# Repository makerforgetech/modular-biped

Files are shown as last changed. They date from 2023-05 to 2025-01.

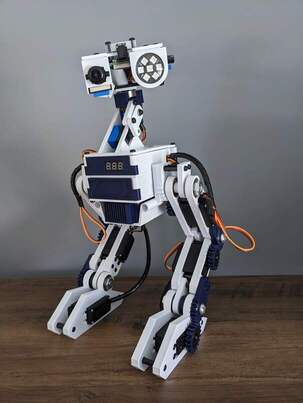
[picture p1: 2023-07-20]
images/full_project_front_thumb.jpg

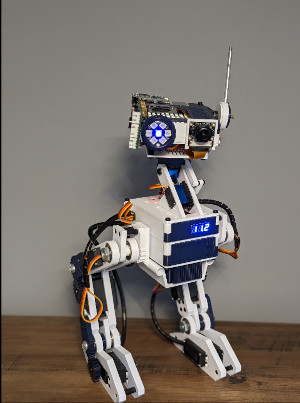
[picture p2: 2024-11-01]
images/full_project_front_pi5_thumb.jpg

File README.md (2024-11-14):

# Open Source, 3D Printable, Modular Bipedal Robot Project

The **Modular Bipedal Robot** project aims to educate and inspire individuals interested in robotics and electronics. This open-source initiative focuses on creating a fully autonomous companion robot with a variety of advanced features.

## Key Features

- **Bipedal Design**: The robot includes articulated legs for bipedal movement.
- **Control Systems**: Utilizes Arduino and Raspberry Pi, managed through custom PCBs.
- **Modular Body**: Configurable body components allow for easy customization and adaptability.
- **Software Modules**:
  - Animation: Handles the animation of the robot, including walking, turning, and other movements.
  - Braillespeak: Converts text to Braille and speaks it using a proprietary audio output using the onboard buzzer.
  - Buzzer: Controls the buzzer for audio output. Includes the ability to play tones and melodies.
  - ChatGPT: Uses the OpenAI GPT models to process text based on user input.
  - Logging: Logs data to a file for debugging and analysis.
  - Motion Detection: Handles motion detection using an onboard microwave motion sensor.
  - Neopixel: Controls the onboard Neopixel LEDs for visual feedback.
  - PiServo: Controls the servos connected to the Raspberry Pi.
  - PiTemperature: Reads the temperature from the integrated temperature sensor on the Raspberry Pi.
  - RTLSDR: Uses an RTL-SDR dongle to receive and process radio signals.
  - Serial Connection: Handles serial communication between the Raspberry Pi and Arduino.
  - Servos: Controls the servos connected to the Arduino via the Raspberry Pi and the serial connection.
  - Tracking: Uses computer vision to track objects and faces using the onboard camera.
  - Translator: Translates text between languages using the Google Translate API.
  - TTS: Converts text to speech using the onboard speaker.
  - Viam: Uses the VIAM API to integrate Viam modules for additional functionality.
  - Vision: Handles image processing and computer vision tasks using the onboard IMX500 Raspberry Pi AI camera.
  - [Read more](https://github.com/makerforgetech/modular-biped/wiki/Software#modules)!

## Project Background

The Modular Biped Robot Project is designed to provide a flexible and modular framework for robotics development using Python and C++ on the Raspberry Pi and Arduino platforms. It aims to enable developers, robotics enthusiasts, and curious individuals to experiment, create, and customize their own biped robots. With a range of features and functionalities and the option to add your own easily, the Modular Biped Robot Project offers an exciting opportunity to explore the world of robotics.

## Modularity

The open source framework is designed for flexibility, allowing users to easily add or remove components to suit their specific needs. Comprehensive [guides](https://github.com/makerforgetech/modular-biped/wiki/Software#creating-a-module) are provided for integrating new modules seamlessly.

## Resources

- **Documentation**: For detailed information, visit the project’s GitHub wiki: [Modular Biped Documentation](https://github.com/makerforgetech/modular-biped/wiki)
- **Code**: Check out the modular open source software on [GitHub](https://github.com/makerforgetech/modular-biped)
- **YouTube Playlist**: Explore the development process through our build videos: [Watch on YouTube](https://www.youtube.com/watch?v=2DVJ5xxAuWY&list=PL_ua9QbuRTv6Kh8hiEXXVqywS8pklZraT)
- **Community**: Have a question or want to show off your build? Join the communities on [GitHub](https://bit.ly/maker-forge-community) and [Discord](https://bit.ly/makerforge-community)!

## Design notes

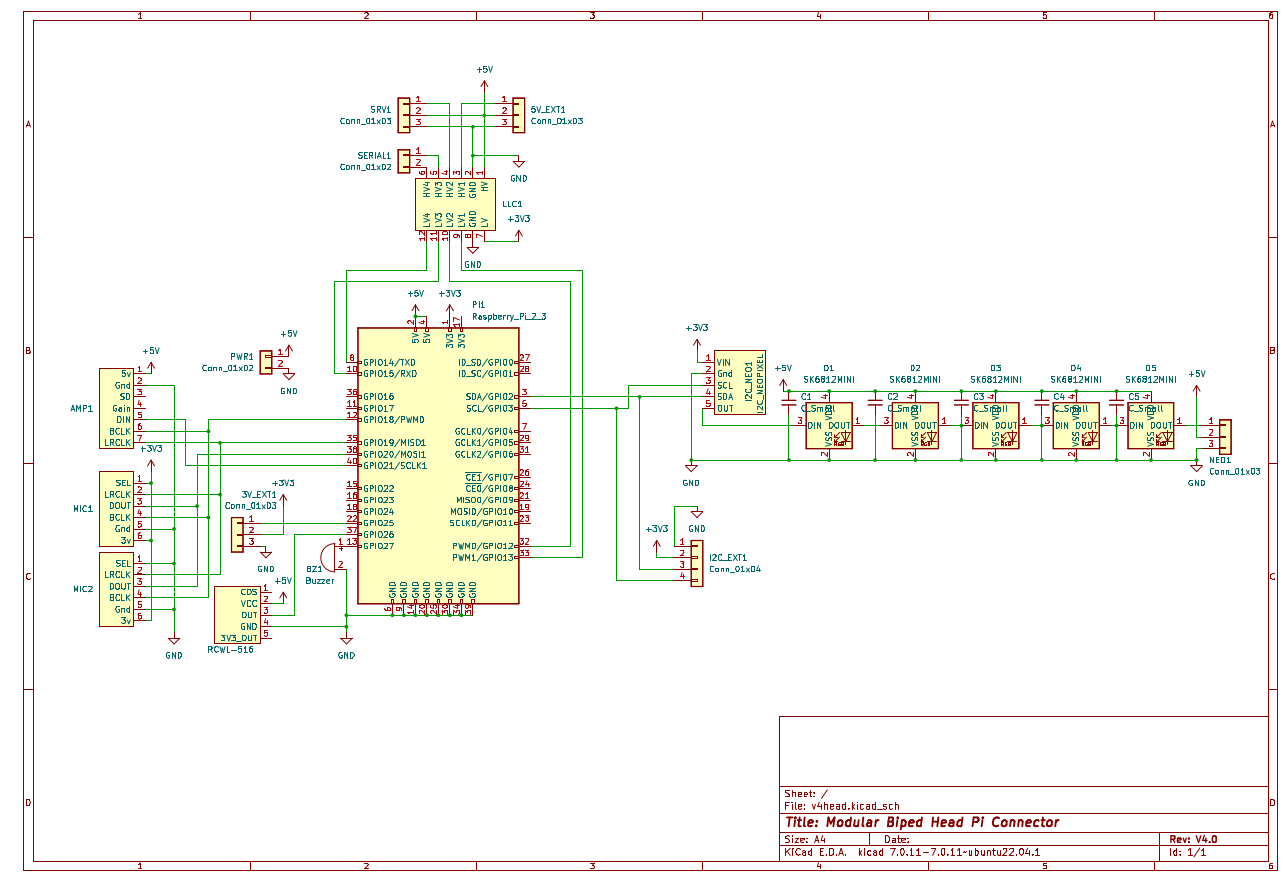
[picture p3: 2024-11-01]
circuits/v4/Head/head_schematic.png

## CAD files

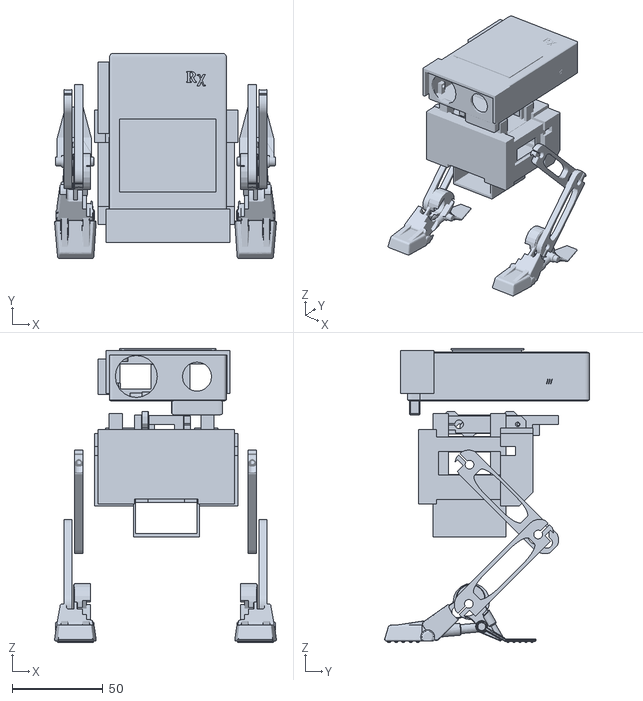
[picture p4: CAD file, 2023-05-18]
3d_prints/v2/complete.stl
122.0 x 112.7 x 161.6

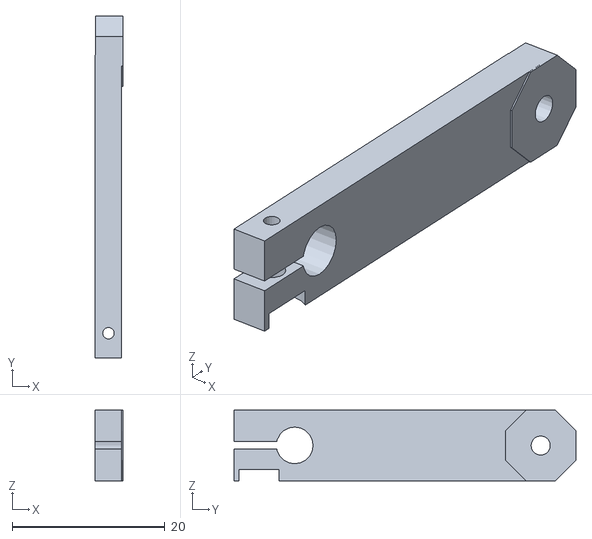
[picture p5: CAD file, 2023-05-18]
3d_prints/v2/neck_extension.stl
3.60 x 44.8 x 9.25

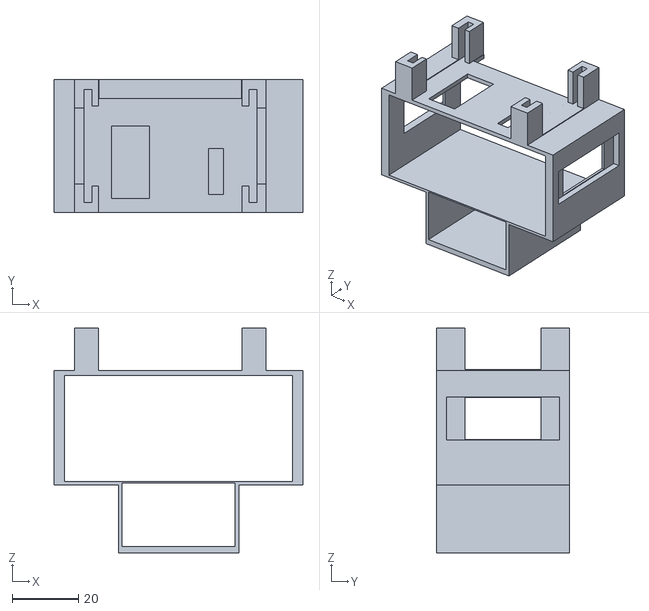
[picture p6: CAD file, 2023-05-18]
3d_prints/v2/skeleton.stl
75.0 x 40.0 x 67.8

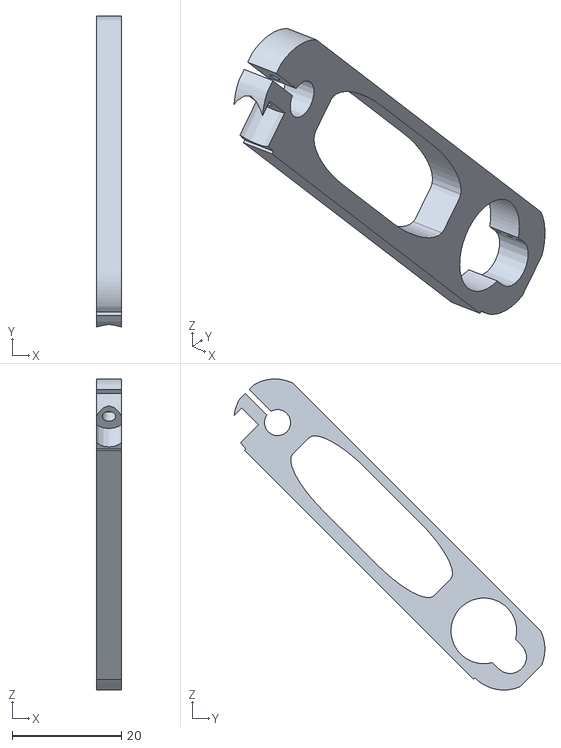
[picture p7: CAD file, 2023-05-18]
3d_prints/v2/right_leg_upper.stl
4.50 x 56.9 x 56.9

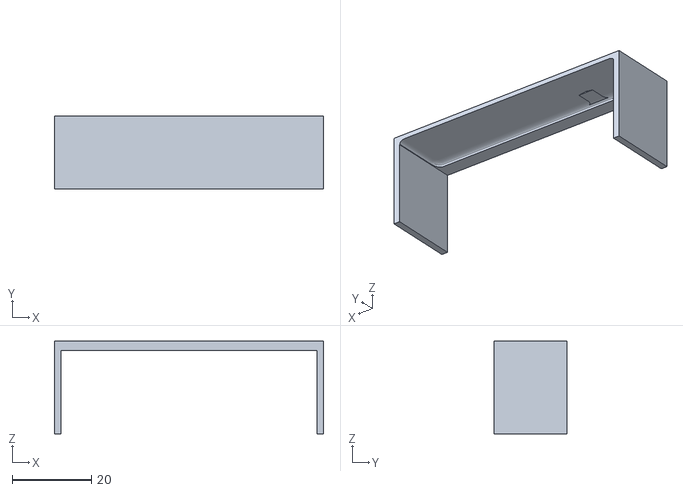
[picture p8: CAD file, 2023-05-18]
3d_prints/v2/head_visor.stl
68.0 x 18.5 x 23.5

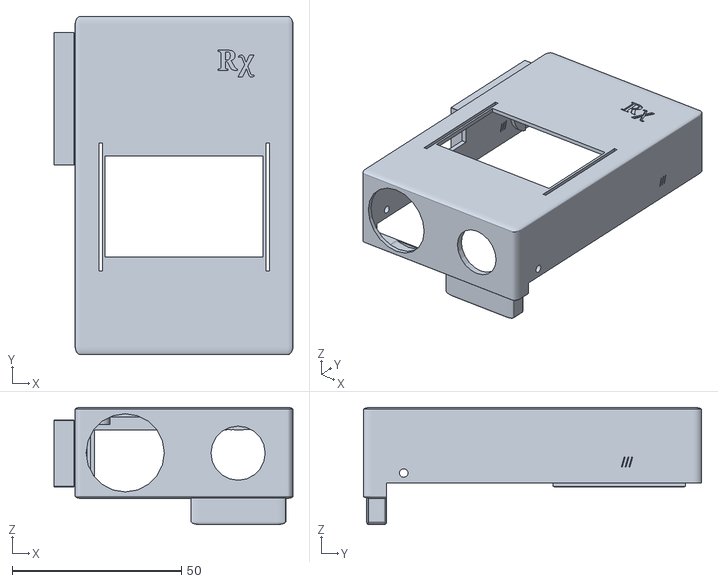
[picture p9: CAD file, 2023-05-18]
3d_prints/v2/head_top.stl
70.6 x 100.0 x 34.7

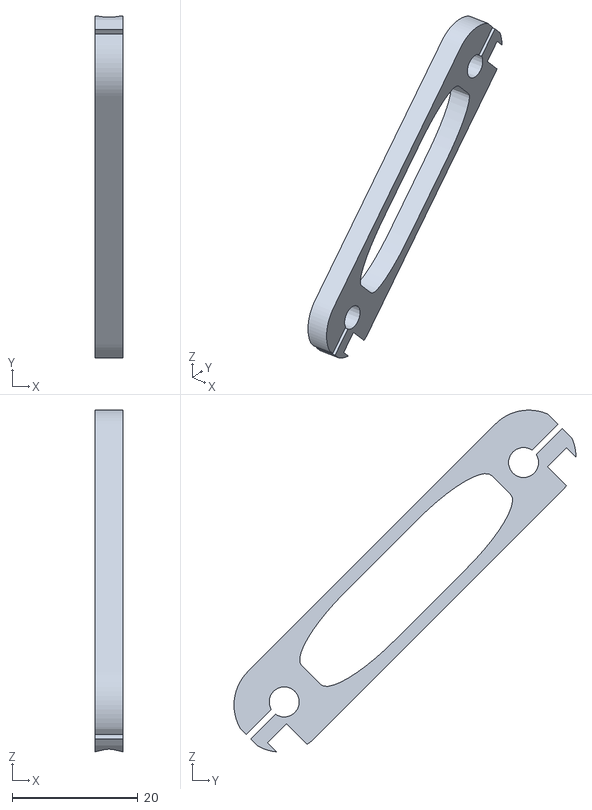
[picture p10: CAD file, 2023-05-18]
3d_prints/v2/left_leg_lower.stl
4.50 x 54.4 x 54.4

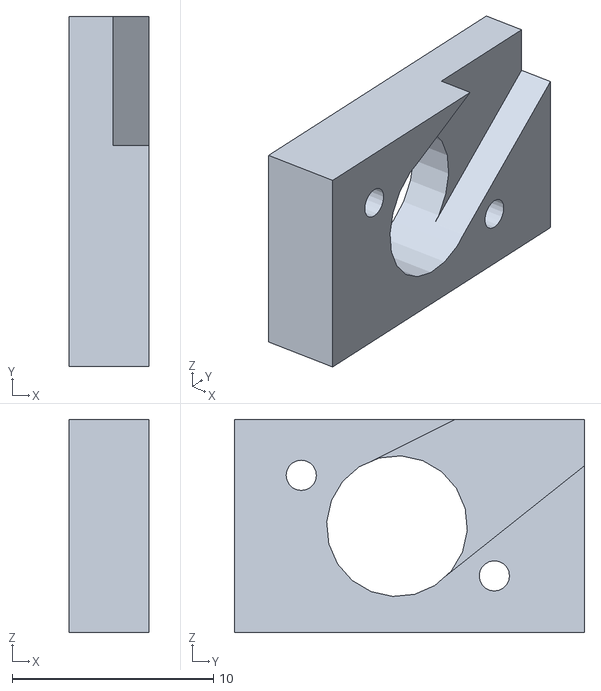
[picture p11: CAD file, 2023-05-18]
3d_prints/v2/neck_tilt_mount.stl
4.00 x 17.4 x 10.6

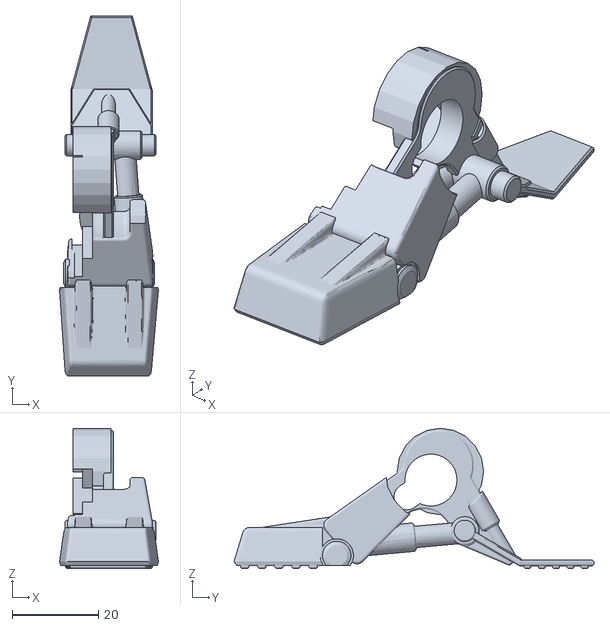
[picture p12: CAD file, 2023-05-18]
3d_prints/v2/left_foot.stl
22.9 x 83.3 x 32.5

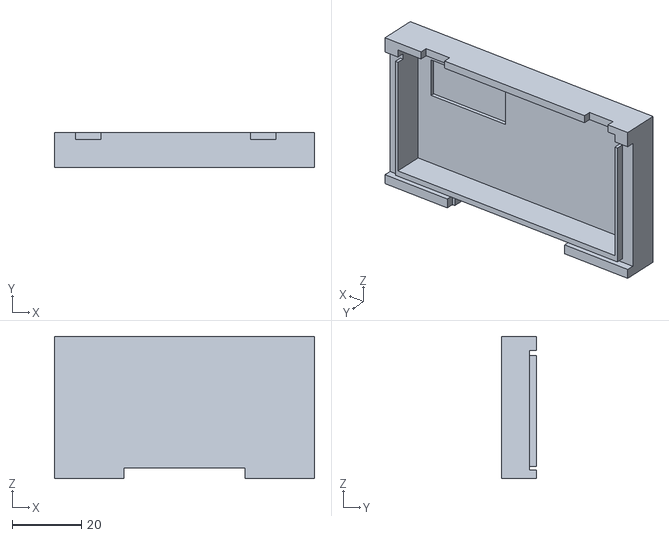
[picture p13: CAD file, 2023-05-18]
3d_prints/v2/front_case.stl
75.0 x 10.0 x 41.0

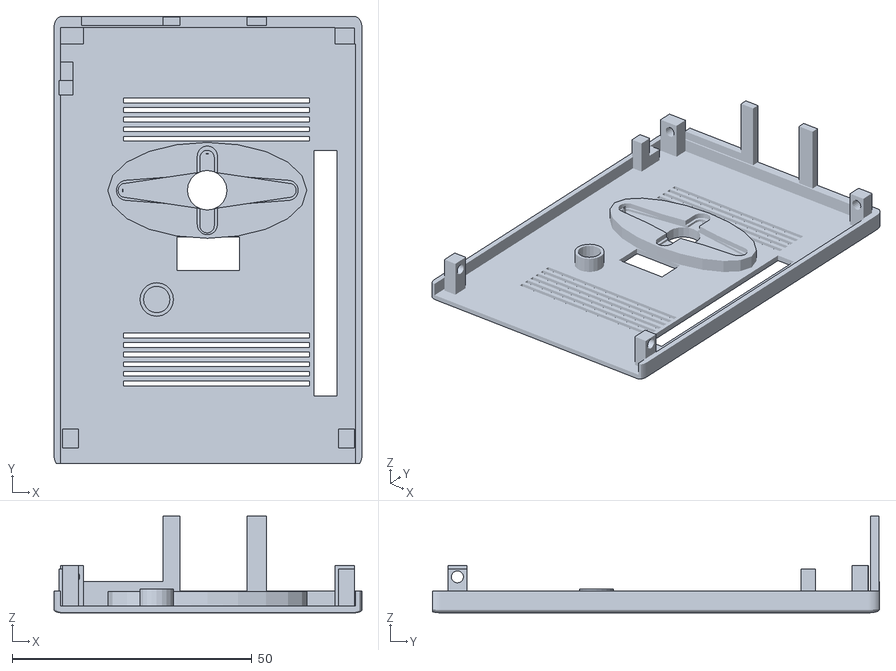
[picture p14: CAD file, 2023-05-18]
3d_prints/v2/head_bottom.stl
64.2 x 93.2 x 20.1

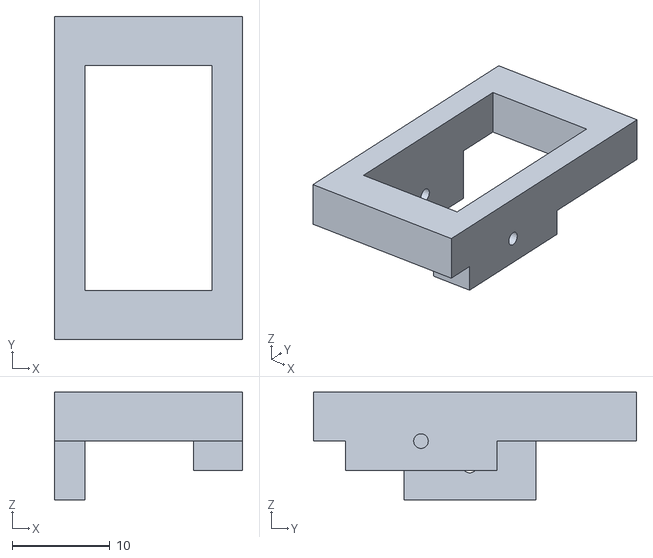
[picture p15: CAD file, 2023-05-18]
3d_prints/v2/neck_servo_mount.stl
19.2 x 33.0 x 11.0

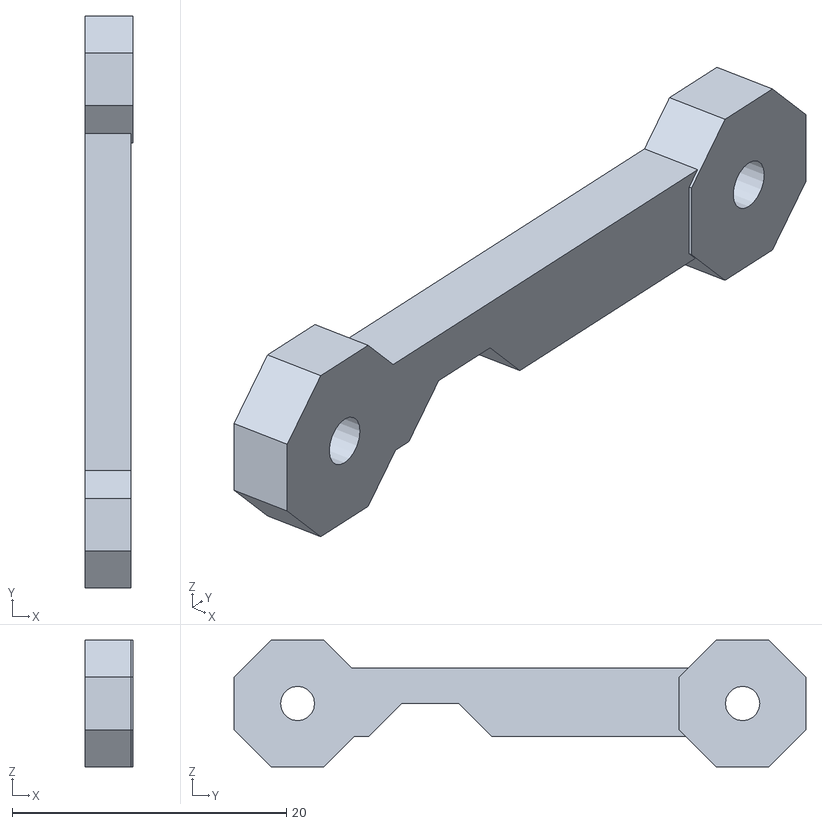
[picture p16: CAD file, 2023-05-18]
3d_prints/v2/neck_tilt_upper.stl
3.50 x 41.7 x 9.24

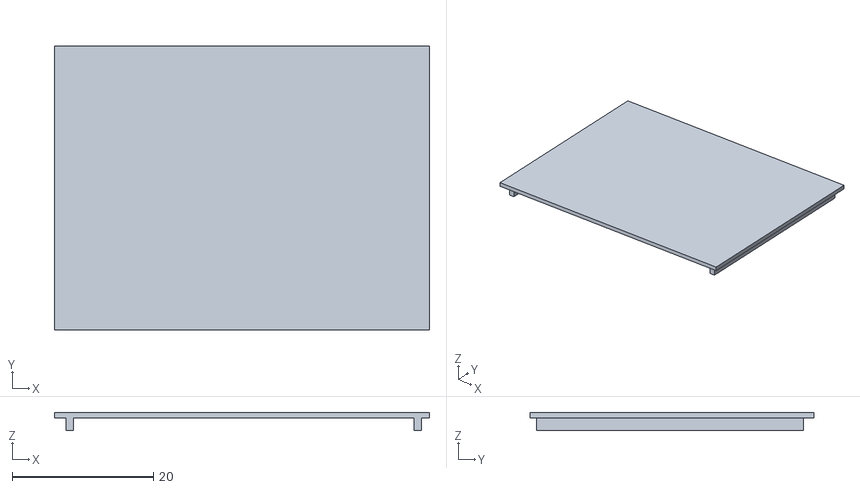
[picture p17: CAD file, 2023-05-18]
3d_prints/v2/head_lid.stl
53.1 x 40.2 x 2.60

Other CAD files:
3d_prints/v2/left_leg_upper.stl
3d_prints/v2/right_leg_lower.stl
3d_prints/v2/right_foot.stl
3d_prints/v2/back_case.stl
3d_prints/v2/neck_tilt_lower.stl

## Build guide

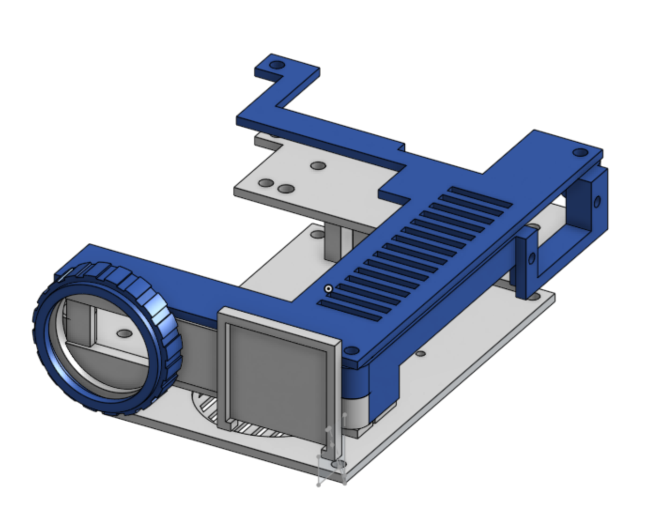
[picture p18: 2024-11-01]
images/assembly_head.png

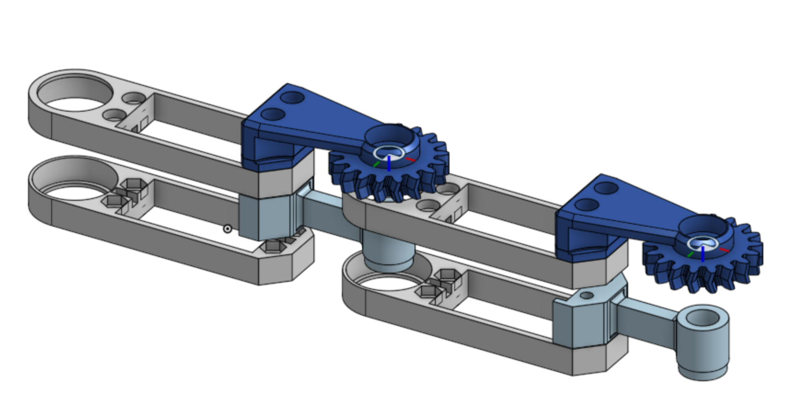
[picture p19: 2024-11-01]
images/assembly_leg.png

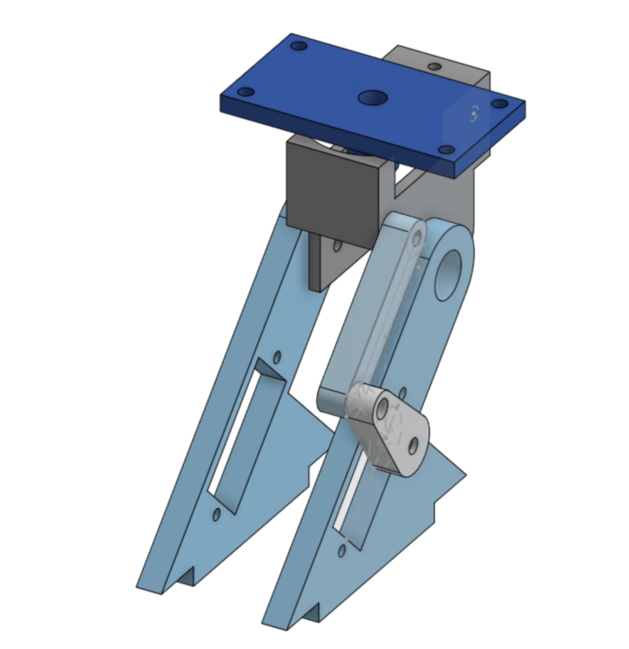
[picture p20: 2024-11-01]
images/assembly_neck.png

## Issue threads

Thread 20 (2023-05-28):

Serial communication between Pi and Arduino

danic85, 2023-05-28:
In branch `v3`, the code has not been fully updated to allow the Pi to take control of the arduino servo positions and suspend random animations from the arduino.

Impact:
The face tracking will not function, or any animations initiated from the Pi.

Additionally, the battery monitor is not implemented in code, although the code for v2 is in place on the Pi.

danic85, 2023-05-29:
I have started a new feature branch for this work until it is stable, progress here:

https://github.com/dmt-labs/modular-biped/pull/21/files

Closed 2023-07-18.

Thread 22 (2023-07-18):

Low battery monitor non-functional

danic85, 2023-07-18:
This has not been updated since v2. Code exists but has not been tested.

danic85, 2024-10-31:
Archiving as this module is not currently in use.

Closed 2024-10-31.

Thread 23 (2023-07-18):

Raspberry Pi Leg control disabled

danic85, 2023-07-18:
See PR:

https://github.com/dmt-labs/modular-biped/pull/21#discussion_r1214812900

This can be re-enabled but it has not been tested.

Currently Arduino is solely responsible for leg positions

danic85, 2024-10-31:
This is no longer the case: although the Pi does not currently control the servos, it can if needed

Closed 2024-10-31.

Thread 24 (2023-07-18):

Face tracking issues

danic85, 2023-07-18:
In v3 the face tracking is not functioning correctly.

The code exists from v2 but has not been adjusted to work with new hardware.

Current behaviour is the head moves to attempt to track face but is not entirely successful.

danic85, 2023-07-31:
This has been updated and works reliably with `debug` mode activated in the vision config. When other modules are also enabled the tracking becomes unpredictable.

Closed 2024-10-31.

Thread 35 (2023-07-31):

Speech recognition issues

danic85, 2023-07-31:
When using speech recognition on `develop` branch an error occurs that not only crashes the app but also causes the Raspberry Pi taskbar to disappear. There is no way to recover this that I can find.

I will add the error here once I can get a copy.

I have disabled the module in `develop` temporarily.

danic85, 2023-07-31:
Similar issue: https://github.com/Uberi/speech_recognition/issues/71

Closed 2024-10-31.

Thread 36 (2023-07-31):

Occasional error when testing i2c neopixels

danic85, 2023-07-31:
There is an error with the i2c neopixel driver when the script is executed multiple times. It appears to be related to the software needing to release the hardware before it can be used again.

Error will be posted soon.

Workaround is to wait for a few seconds then try again.

danic85, 2024-10-31:
Closing as this does not have a major impact, and I haven't seen it recently.

Closed 2024-10-31.

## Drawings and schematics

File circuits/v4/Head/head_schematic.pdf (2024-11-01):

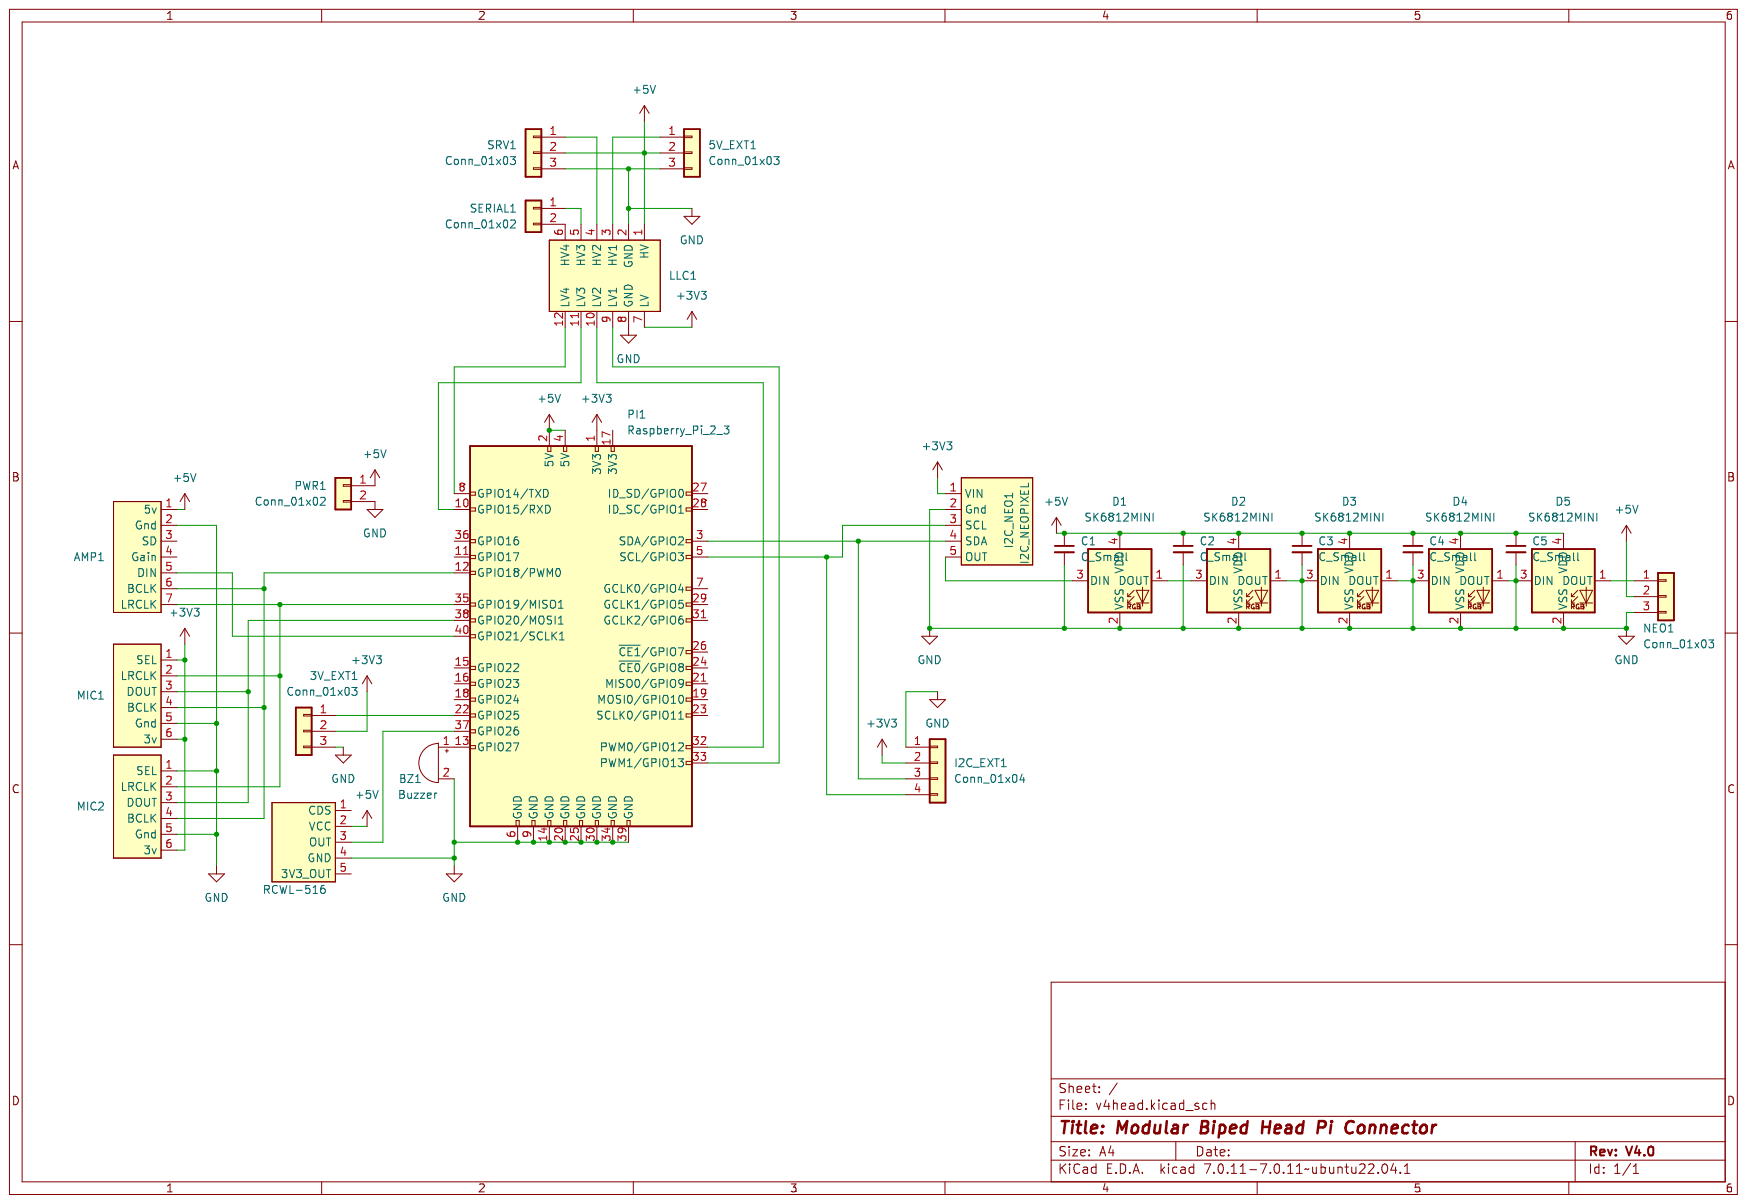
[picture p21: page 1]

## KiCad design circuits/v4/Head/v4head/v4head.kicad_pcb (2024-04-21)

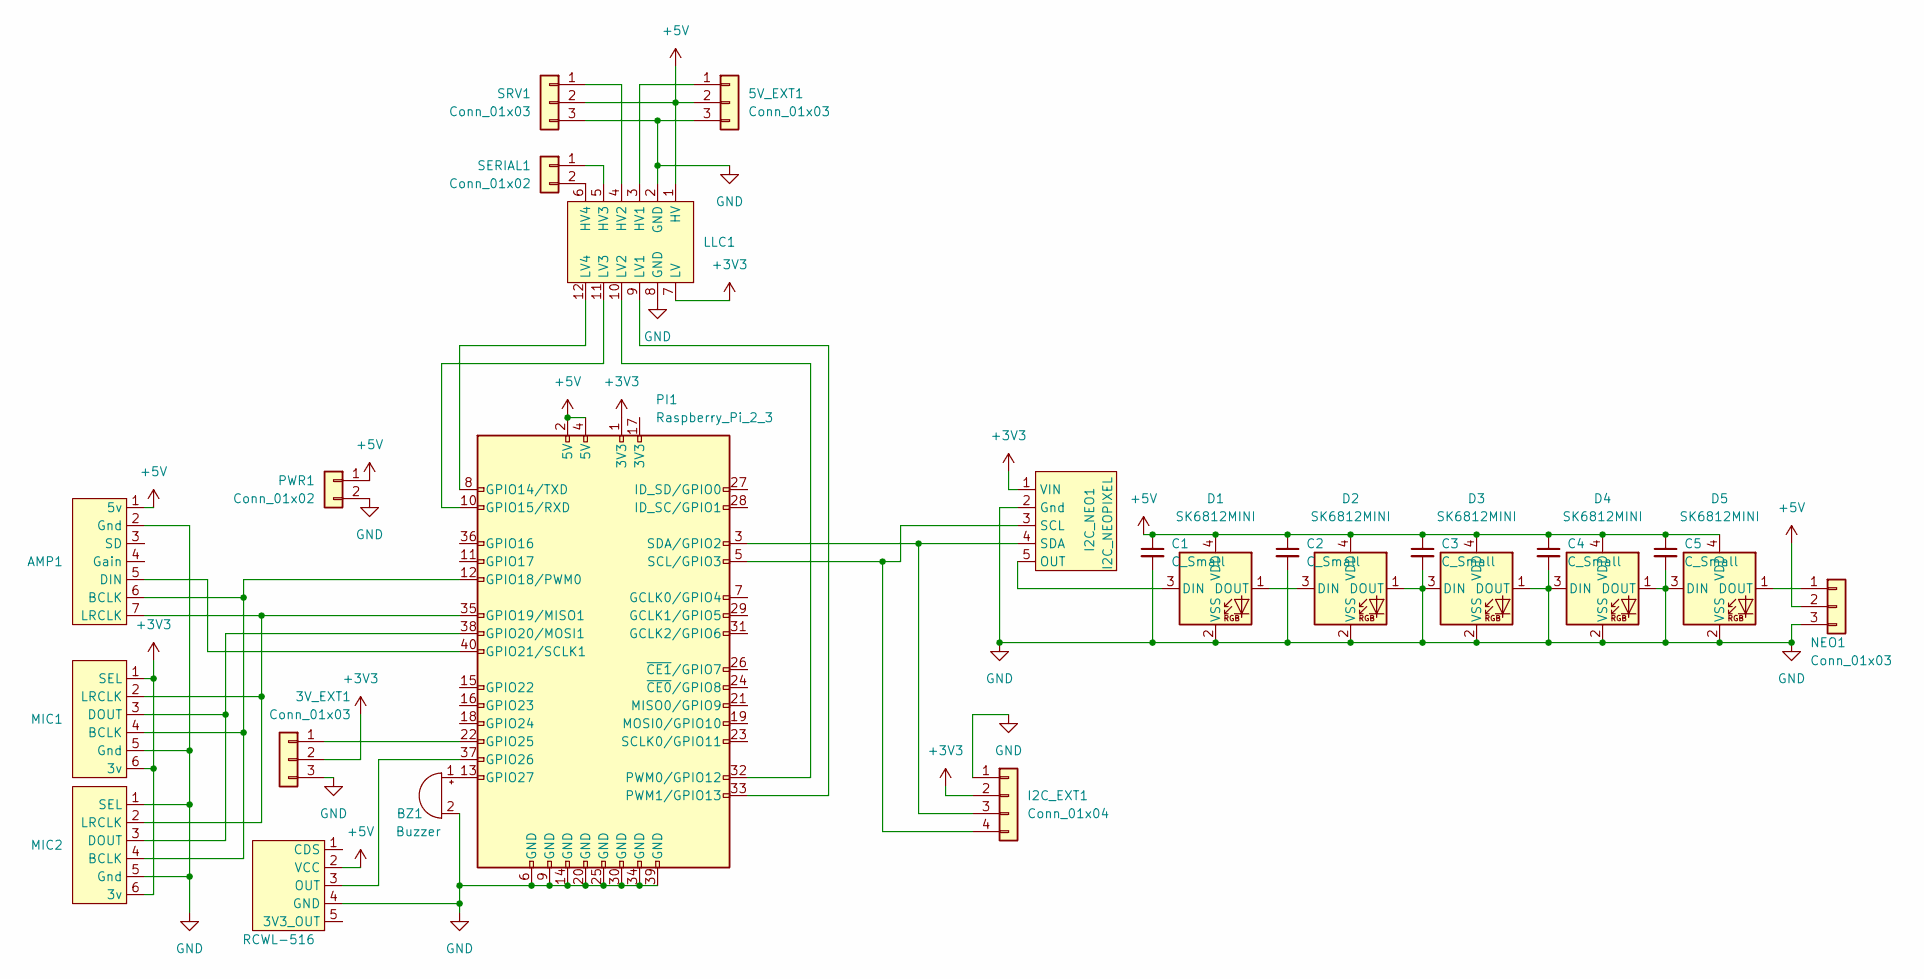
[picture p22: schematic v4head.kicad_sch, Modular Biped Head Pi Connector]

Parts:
3V_EXT1, 5V_EXT1: Conn_01x03; JST_XH_B3B-XH-A_1x03_P2.50mm_Vertical
AMP1: MAX98357
BZ1: Buzzer; Buzzer_12x9.5RM7.6
C1, C2, C3, C4, C5: C_Small; C_0201_0603Metric
D1, D2, D3, D4, D5: SK6812MINI; LED_SK6812MINI_PLCC4_3.5x3.5mm_P1.75mm
I2C_EXT1: Conn_01x04; JST_XH_B4B-XH-A_1x04_P2.50mm_Vertical
I2C_NEO1: I2C_NEOPIXEL
LLC1: LCC_BIDIRECTIONAL
MIC1, MIC2: SPH0645LM4H
NEO1: Conn_01x03; JST_XH_B3B-XH-A_1x03_P2.50mm_Vertical
PI1: Raspberry_Pi_2_3; PinHeader_2x20_P2.54mm_Vertical
PWR1: Conn_01x02; JST_XH_B2B-XH-A_1x02_P2.50mm_Vertical
RCWL-516: RCWL-0516_MIN
SERIAL1: Conn_01x02; JST_XH_B2B-XH-A_1x02_P2.50mm_Vertical
SRV1: Conn_01x03; PinHeader_1x03_P2.54mm_Vertical

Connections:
+3V3: 3V_EXT1.2, I2C_EXT1.2, I2C_NEO1.1 (VIN), LLC1.7 (LV), MIC1.1 (SEL), MIC1.6 (3v), MIC2.6 (3v), PI1.1 (3V3)
+5V: 5V_EXT1.2, AMP1.1 (5v), C1.1, C2.1, C3.1, C4.1, C5.1, D1.4 (VDD), D2.4 (VDD), D3.4 (VDD), D4.4 (VDD), D5.4 (VDD), LLC1.1 (HV), NEO1.2, PI1.2 (5V), PI1.4 (5V), PWR1.1, RCWL-516.2 (VCC), SRV1.2
GND: 3V_EXT1.3, 5V_EXT1.3, AMP1.2 (Gnd), BZ1.2 (+), C1.2, C2.2, C3.2, C4.2, C5.2, D1.2 (VSS), D2.1 (DOUT), D2.2 (VSS), D3.1 (DOUT), D3.2 (VSS), D3.3 (DIN), D4.1 (DOUT), D4.2 (VSS), D4.3 (DIN), D5.2 (VSS), D5.3 (DIN), I2C_EXT1.1, I2C_NEO1.2 (Gnd), LLC1.2 (GND), LLC1.8 (GND), MIC1.5 (Gnd), MIC2.1 (SEL), MIC2.5 (Gnd), NEO1.3, PI1.6 (GND), PI1.9 (GND), PI1.14 (GND), PI1.20 (GND), PI1.25 (GND), PI1.30 (GND), PI1.34 (GND), PI1.39 (GND), PWR1.2, RCWL-516.4 (GND), SRV1.3
unnamed: 3V_EXT1.1, PI1.22 (GPIO25)
unnamed: 5V_EXT1.1, LLC1.3 (HV1)
unnamed: AMP1.6 (BCLK), MIC1.4 (BCLK), MIC2.4 (BCLK), PI1.12 (GPIO18/PWM0)
unnamed: AMP1.5 (DIN), PI1.40 (GPIO21/SCLK1)
unnamed: AMP1.7 (LRCLK), MIC1.2 (LRCLK), MIC2.2 (LRCLK), PI1.35 (GPIO19/MISO1)
unnamed: BZ1.1 (-), PI1.13 (GPIO27)
unnamed: D1.3 (DIN), I2C_NEO1.5 (OUT)
unnamed: D1.1 (DOUT), D2.3 (DIN)
unnamed: D5.1 (DOUT), NEO1.1
unnamed: I2C_EXT1.3, I2C_NEO1.4 (SDA), PI1.3 (SDA/GPIO2)
unnamed: I2C_EXT1.4, I2C_NEO1.3 (SCL), PI1.5 (SCL/GPIO3)
unnamed: LLC1.4 (HV2), SRV1.1
unnamed: LLC1.5 (HV3), SERIAL1.1
unnamed: LLC1.6 (HV4), SERIAL1.2
unnamed: LLC1.9 (LV1), PI1.33 (PWM1/GPIO13)
unnamed: LLC1.10 (LV2), PI1.32 (PWM0/GPIO12)
unnamed: LLC1.11 (LV3), PI1.10 (GPIO15/RXD)
unnamed: LLC1.12 (LV4), PI1.8 (GPIO14/TXD)
unnamed: MIC1.3 (DOUT), MIC2.3 (DOUT), PI1.38 (GPIO20/MOSI1)
unnamed: PI1.37 (GPIO26), RCWL-516.3 (OUT)

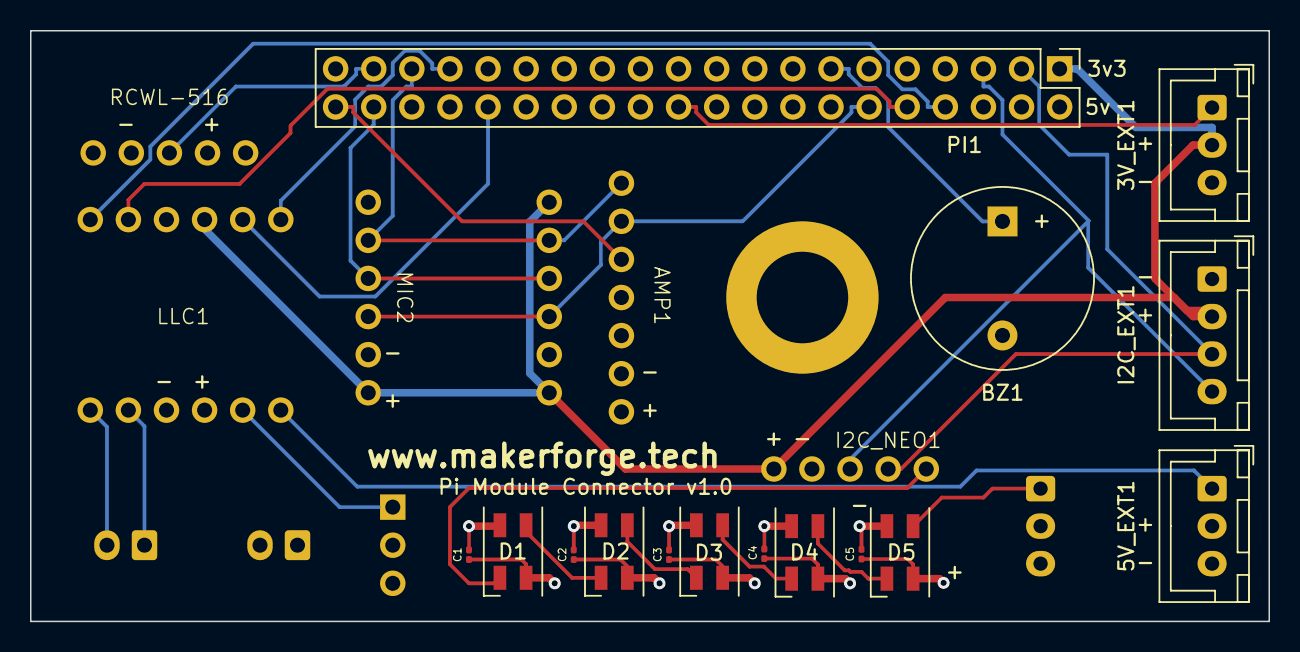
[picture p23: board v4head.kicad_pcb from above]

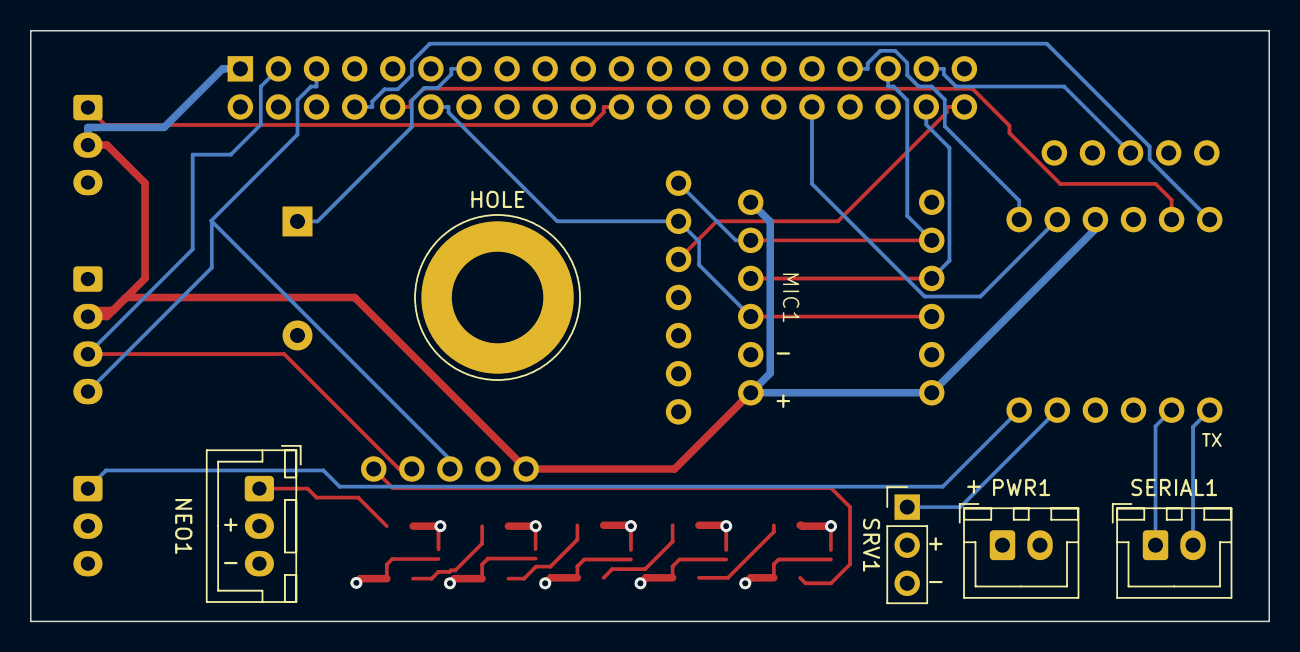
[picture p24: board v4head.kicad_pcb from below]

Board: 4 copper layers, 82.5 x 39.4 mm, 26 parts (6 on the bottom side), 23 nets.

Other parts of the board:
HOLE: Banana_Jack_1Pin

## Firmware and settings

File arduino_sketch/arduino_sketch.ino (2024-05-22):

/**
 * @file arduino_sketch2.ino
 * @brief Arduino sketch to control a 9 servo robot
 * @details This sketch animates a 9 servo bipedal robot using the ServoEasing library.
 * See the README.md file for more information.
 */

#include <Arduino.h>
#include "ServoEasing.hpp" // Must be here otherwise method fails: setEaseToForAllServosSynchronizeAndStartInterrupt
#include "Config.h"
#include "Order.h"
#include "PiConnect.h"
#include "ServoManager.h"
#ifdef MPU6050_ENABLED
#include "Mpu6050.h"
#endif

// #define DEBUG

PiConnect pi;
ServoManager servoManager;
#ifdef MPU6050_ENABLED
Mpu6050 tilt;
#endif

bool isResting = false;
// boot time in millis
unsigned long bootTime;
// wait start time in millis
unsigned long sleepTime;

boolean calibrateRest = false;

bool shouldMove = false;

bool piControl = false;

void setup()
{
  // Init LED pin
  pinMode(LED_BUILTIN, OUTPUT);
  pinMode(11, OUTPUT);   // sets the digital pin as output
  digitalWrite(11, LOW); // sets the digital pin on
  // Init boot time for sleep function
  bootTime = millis();
  // Init serial
  Serial.begin(115200);


  pinMode(backpackPin, INPUT_PULLUP); // sets the digital pin as input
  if (digitalRead(backpackPin) == LOW) // Check once on startup
  {
    Serial.println("Backpack detected");
    backpack = true;
  }

  pinMode(restrainPin, INPUT_PULLUP); // sets the digital pin as input
  if (digitalRead(restrainPin) == LOW) // Check once on startup
  {
    Serial.println("Restraint detected");
    restrainingBolt = true;
  }

  // Init ServoManager
  servoManager.doInit();
  servoManager.setSpeed(SERVO_SPEED_MIN);

  #ifdef MPU6050_ENABLED
  tilt.doInit();
  #endif

  // Seed random number generator
  randomSeed(analogRead(0));

  // allTo90();

  // Move to rest position + calculate IK and store as rest position
  // doRest();

  // Custom log message (enable DEBUG in Config.h to see this)
  cLog("Start loop");
}
/**
 * @brief Set all servos to 90 degrees for mechanical calibration. Wait for 20 seconds.
 */
void allTo90()
{
  cLog("All at 90");
  servoManager.moveServos(PosConfig);
  setEaseToForAllServosSynchronizeAndStartInterrupt(servoManager.getSpeed());
  while (ServoEasing::areInterruptsActive())
  {
    blinkLED();
  }
  delay(20000);
}

/**
 * @brief Move to rest position. Either using stored values or by calculating using inverse kinematics and storing result for next time.
 */
void doRest()
{
  cLog("Resting");

  // Reset to slow speed
  servoManager.setSpeed(SERVO_SPEED_MIN);
  if (calibrateRest == false)
  {
    servoManager.moveServos(PosRest);
  }
  else
  {
    // Mid value between LEG_IK_MIN and LEG_IK_MAX
    float mid = LEG_IK_MIN + ((LEG_IK_MAX - LEG_IK_MIN) / 2);
    servoManager.moveLegsAndStore(mid, 0, PosRest); // Move legs and store as rest position
// iterate over PosRest and output values:
#ifdef DEBUG
    for (int i = 0; i < 9; i++)
    {
      Serial.print(PosRest[i]);
      Serial.print(", ");
    }
    Serial.println();
#endif
    calibrateRest = false;
  }
  shouldMove = true;
  // setEaseToForAllServosSynchronizeAndStartInterrupt(servoManager.getSpeed());
}

void stationarySteps() {
  int left[SERVO_COUNT] = {PosMin[0], PosMin[1], PosMin[2], PosMax[3], PosMax[4], PosMax[5]};
  int right[SERVO_COUNT] = {PosMax[0], PosMax[1], PosMax[2], PosMin[3], PosMin[4], PosMin[5]};
  uint16_t speed = SERVO_SPEED_MIN; // 20 - 60 recommended
  unsigned long delayTime = 200;
  servoManager.setSpeed(speed);
  boolean moveLeft = true;
  while (true)
  {
    if (moveLeft)
      servoManager.moveServos(left);
    else
      servoManager.moveServos(right);

    setEaseToForAllServosSynchronizeAndStartInterrupt(servoManager.getSpeed());

    while (ServoEasing::areInterruptsActive())
    {
      blinkLED();
    }

    delay(delayTime);
  }
}

#ifdef MPU6050_ENABLED
void hipAdjust()
{
  tilt.read();
  //Serial.println(tilt.getPitch());
  servoManager.hipAdjust(tilt.getPitch());
  setEaseToForAllServosSynchronizeAndStartInterrupt(servoManager.getSpeed());
}
#endif

void loop()
{
  #ifdef SERVO_CALIBRATION_ENABLED
    servoManager.calibrate();
  #endif

  #ifdef MPU6050_ENABLED
  hipAdjust();
  #endif
  //  This needs to be here rather than in the ServoManager, otherwise it doesn't work.
  while (ServoEasing::areInterruptsActive())
  {
    blinkLED();
  }

  // Check for orders from pi
  bool receiving = getOrdersFromPi();
  while(receiving) 
  {
    piControl = true;
    delay(50); // Wait a short time for any other orders
    receiving = getOrdersFromPi();
    shouldMove = !receiving; // Only move when there are no other orders
  }
  
  // Once all orders received (or animating without orders)
  if (shouldMove)
  {
    setEaseToForAllServosSynchronizeAndStartInterrupt(servoManager.getSpeed());
    shouldMove = false;
  }

  // if not sleeping, animate randomly
  // Orders from pi will set sleep time so that the animation does not take precedence
  if (!isSleeping())
  {
    if (isResting && piControl == false) // Only do this if the Pi is not in control (i.e. switched off)
    {
      #ifdef ANIMATE_ENABLED
      animateRandomly();
      #endif
    }
    else
    {
      // doRest();
      isResting = true;
      setSleep(random(1000, 5000));
    }
  }
  
}

void setSleep(unsigned long length)
{
  sleepTime = millis() - bootTime + length;
}

boolean isSleeping()
{
  return millis() - bootTime < sleepTime;
}

void animateRandomly()
{
  cLog("Animating");
  isResting = false;
  servoManager.setSpeed(SERVO_SPEED_MIN);

  // Look around randomly and move legs to react
  servoManager.moveServos(PosLookRandom);
  // If head looks down, move legs up, and vice versa
  float headTiltOffset = ServoEasing::ServoEasingNextPositionArray[7] - 90;
  // Attempt to compensate movement of head by adjusting leg height
  // Scale headTiltOffset value between 0 and 180 (inverted) to scale of LEG_IK_MIN and LEG_IK_MAX
  float legHeight = map(headTiltOffset, 180, 0, LEG_IK_MIN, LEG_IK_MAX);
  // Move legs to that height
  // servoManager.moveLegs(LEG_IK_MAX, 0);
  servoManager.moveServos(PosStand);
  shouldMove = true;
#ifdef DEBUG
  Serial.print("Moving legs ");
  Serial.print(legHeight);
  Serial.print(" as head tilt was ");
  Serial.println(headTiltOffset);
#endif
}

boolean getOrdersFromPi()
{
  if (Serial.available() == 0)
    //PiConnect::write_order(ERROR);
    return false;
  cLog("Order received: ", false);

  // The first byte received is the instruction
  Order order_received = PiConnect::read_order();
  cLog((String)order_received);
  if (order_received == HELLO)
  {
    // If the cards haven't say hello, check the connection
    if (!pi.isConnected())
    {
      pi.setConnected(true);
      PiConnect::write_order(HELLO);
    }
    else
    {
      // If we are already connected do not send "hello" to avoid infinite loop
      PiConnect::write_order(ALREADY_CONNECTED);
    }
  }
  else if (order_received == ALREADY_CONNECTED)
  {
    pi.setConnected(true);
  }
  else
  {
    switch (order_received)
    {
      case SERVO:
      case SERVO_RELATIVE:
      {
        int servo_identifier = PiConnect::read_i8();
        int servo_angle_percent = PiConnect::read_i16();
  #ifdef DEBUG
        PiConnect::write_order(SERVO);
        PiConnect::write_i8(servo_identifier);
        PiConnect::write_i16(servo_angle_percent);
  #endif
        // sleep animations for 2 seconds to allow pi to control servos
        setSleep(2000);
        servoManager.moveSingleServoByPercentage(servo_identifier, servo_angle_percent, order_received == SERVO_RELATIVE);
        return true;
      }
      case PIN:
      {
        int pin = PiConnect::read_i8();
        int value = PiConnect::read_i8();
        pinMode(pin, OUTPUT);
        digitalWrite(pin, value);
        break;
      }
      case READ:
      {
        int pin = PiConnect::read_i8();
        pinMode(pin, INPUT);
        long value = analogRead(pin);
        PiConnect::write_i16(value);
        break;
      }
      // Unknown order
      default:
      {
        PiConnect::write_order(order_received);
        // PiConnect::write_i16(404);
      }
    }
  }
  return false;
}

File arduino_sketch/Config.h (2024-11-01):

#ifndef CONFIG_H
#define CONFIG_H
/**
 * @file config.h
 * @brief Configuration file for the Arduino sketch.
 * @details This file contains the configuration for the Arduino sketch.
 */
//#define SERVO_CALIBRATION_ENABLED // Enable servo calibration (see ServoManager::calibrate())
//#define SERVO_CALIBRATION_SYMMETRICAL // Calculate and apply equivelant changes on other leg.

#define SERVO_PIN_OFFSET 2 // Legacy, used to identify pin from pi communication
// Left Leg
#define PIN_SLLH 9 // Servo left leg hip
#define PIN_SLLK 10 // Servo left leg knee
#define PIN_SLLA 11 // Servo left leg ankle
// Right Leg
#define PIN_SRLH 6 // Servo right leg hip
#define PIN_SRLK 7 // Servo right leg knee
#define PIN_SRLA 8 // Servo right leg ankle
// Neck
#define PIN_SNT 2 // Servo neck tilt
#define PIN_SNP 3 // Servo neck pan
// Sway
#define PIN_SLLHP 4 // Servo left leg hip pivot (unused)
#define PIN_SRLHP 5 // Servo right leg hip pivot (unused)

#define LEG_LENGTH_SHIN 94.0 // Length of shin
#define LEG_LENGTH_THIGH 94.0 // Length of thigh
#define LEG_LENGTH_FOOT 28.0 // Length of foot

#define HIP_ADJUSTMENT 120 // Starting angle of hip relative to IK model
#define KNEE_ADJUSTMENT 90
#define ANKLE_ADJUSTMENT 85

#define EASING_TYPE EASE_QUADRATIC_IN_OUT
#define ENABLE_EASE_QUADRATIC
#define SERVO_SPEED_MIN 20
#define SERVO_SPEED_MAX 80

// #define DEBUG

#define SERVO_COUNT 8 // Number of servos to be controlled by ServoEasing

#define LEG_IK_MIN 75 // Min solvable height of leg between hip and ankle
#define LEG_IK_MAX 180 // Max solvable height of leg between hip and ankle

#define NOVAL 1000

#define MPU6050_ENABLED // Enable MPU6050
//#define MPU6050_DEBUG // Debug in serial plotter
#define ANIMATE_ENABLED // Enable random animations

// Arrays to store servo min / max positions to avoid mechanical issues due
// NOTE: attach() disregards this, set PosRest to be within range of the servo's physical boundaries
int PosMin[SERVO_COUNT] = {0, 0, 5, 0, 0, 20, 60, 30};
int PosMax[SERVO_COUNT] = {180, 180, 165, 180, 180, 180, 120, 150};
int PosSleep[SERVO_COUNT] = {40, 60, 95, 140, 120, 85, PosMax[7], 90};
//int PrepRestFromSleep[SERVO_COUNT] = {80, PosMin[1], PosMax[2], 100, PosMax[4], PosMin[5], S7_REST, 80, S9_REST};
//int PrepSleepFromRest[SERVO_COUNT] = {S1_REST, S2_REST, S3_REST, S4_REST, S5_REST, S6_REST, S7_REST, 80, S9_REST};

// Starting positions
//0, 3 = HIP
int PosStart[SERVO_COUNT] = {60, 0, 165, 120, 180, 20, 90, 90};

int PosBackpack[SERVO_COUNT] = {45, 90, 165, 135, 90, 20, 90, 90}; // straighten legs and point feet to fit in backpack upright

//int PosRest[SERVO_COUNT] = {S1_REST, S2_REST, S3_REST, S4_REST, S5_REST, S6_REST, S7_REST, S8_REST, S9_REST};
int PosRest[SERVO_COUNT] = {60, 0, 165, 120, 180, 20, 90, 90};

int PosConfig[SERVO_COUNT] = {90, 90, 90, 90, 90, 90, 90, 90};

// Poses
int PosStand[SERVO_COUNT] = {45, 75, 80, 135, 105, 100, NOVAL, NOVAL};
int PosLookLeft[SERVO_COUNT] = {NOVAL, NOVAL, NOVAL, NOVAL, NOVAL, NOVAL, NOVAL, 180};
int PosLookRight[SERVO_COUNT] = {NOVAL, NOVAL, NOVAL, NOVAL, NOVAL,  NOVAL, NOVAL, 0};
int PosLookRandom[SERVO_COUNT] = {NOVAL, NOVAL, NOVAL, NOVAL, NOVAL, NOVAL, -1, -1}; // Made random by calling the function moveRandom() if the value is -1
int PosLookUp[SERVO_COUNT] = {NOVAL, NOVAL, NOVAL, NOVAL, NOVAL, NOVAL, 60, 90};
int PosLookDown[SERVO_COUNT] = {NOVAL, NOVAL, NOVAL, NOVAL, NOVAL, NOVAL, 120, 90};

// Array of poses except PosRest and PosSleep (which are used for initialization and reset of position)
int *Poses[] = {PosStand, PosLookLeft, PosLookRight, PosLookUp, PosLookDown, PosLookRandom};

int backpackPin = PIN_A1;
bool backpack = false;

int restrainPin = 12;
bool restrainingBolt = false;

void blinkLED()
{
    digitalWrite(LED_BUILTIN, HIGH);
    delay(100);
    digitalWrite(LED_BUILTIN, LOW);
    delay(100);
}

/**
 * Custom logging function to avoid having to wrap every Serial.println() in #ifdef DEBUG
*/
void cLog(String message, boolean newline = true)
{
    #ifdef DEBUG
    if (newline)
    {
        Serial.println(message);
    }
    else
    {
        Serial.print(message);
    }
    #endif
}

#endif

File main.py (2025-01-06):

import os, sys
import logging
from time import sleep, time
import signal
# import schedule
from pubsub import pub
from modules.config import Config
from module_loader import ModuleLoader

# Set up logging
logging.basicConfig(filename=os.path.dirname(__file__) + '/app.log', level=logging.INFO, format='%(levelname)s: %(asctime)s %(message)s',
                            datefmt='%m/%d/%Y %I:%M:%S %p') # this doesn't work unless it's here
from modules.logwrapper import LogWrapper

def mode():
    return Config.MODE_KEYBOARD if len(sys.argv) > 1 and sys.argv[1] == 'manual' else Config.MODE_LIVE

def main():
    print('Starting...')
    
    path = os.path.dirname(__file__)
    log = LogWrapper(path=os.path.dirname(__file__))

    # Throw exception to safely exit script when terminated
    signal.signal(signal.SIGTERM, Config.exit)
    
    # Dynamically load and initialize modules
    loader = ModuleLoader(config_folder="config")
    module_instances = loader.load_modules()

    # Add your business logic here using module_instances as needed
    # Example: module_instances[0].some_method()
    # vision = module_instances['vision']
    
    ## output all module instance keys for reference
    # print(module_instances.keys())
    # dict_keys(['ArduinoSerial', 'NeoPx', 'BrailleSpeak', 'Animate', 'Vision', 'PiTemperature', 'Servo_leg_l_hip', 'Servo_leg_l_knee', 'Servo_leg_l_ankle', 'Servo_leg_r_hip', 'Servo_leg_r_knee', 'Servo_leg_r_ankle', 'Servo_tilt', 'Servo_pan', 'Translator', 'Tracking_tracking', 'Sensor', 'Buzzer_buzzer'])

    # Use animate to nod head
    # pub.sendMessage('animate', action='head_nod')
    # sleep(1)
    # pub.sendMessage('animate', action='head_shake')
    
    # Enable translator in log wrapper
    # log.translator = module_instances['Translator'] # Set the translator for the log wrapper

    # Use braillespeak to say hi
    # pub.sendMessage('speak', msg="Hi")
    
    # Play happy birthday with buzzer
    # pub.sendMessage('play', song="happy birthday") # Also available: 'merry christmas'

    
    # Check temperature of Raspberry Pi
    # pub.subscribe(self.handleTemp, 'temperature') # handleTemp should accept 'value' as a parameter
    
    # Move pi servo
    # pub.sendMessage('piservo:move', angle=30)
    # pub.sendMessage('piservo:move', angle=-30)
    
    # Move servo
    # pub.sendMessage('servo:<identifier>:mv', percentage=50) # e.g. servo:pan:mv
    # pub.sendMessage('servo:<identifier>:mvabs', percentage=50) # Absolute position. e.g. servo:pan:mvabs

    # Test emotion analysis
    # pub.sendMessage('speech', text='I am so happy today!')
    
    # Test speech input
    # pub.sendMessage('speech:listen')

    # Start loops or other tasks
    pub.sendMessage('log', msg="[Main] Loop started")

    second_loop = time()
    ten_second_loop = time()
    minute_loop = time()
    loop = True
    
    try:
        while loop:
            pub.sendMessage('loop')
            if time() - second_loop > 1:
                second_loop = time()
                pub.sendMessage('loop:1')
            if time() - ten_second_loop > 10:
                ten_second_loop = time()
                pub.sendMessage('loop:10')
            if time() - minute_loop > 60:
                minute_loop = time()
                pub.sendMessage('loop:60')
                # schedule.run_pending()

    except Exception as ex:
        logging.error(f"Exception: {ex}", exc_info=True)
        loop = False

    finally:
        pub.sendMessage("exit")
        pub.sendMessage("log", msg="[Main] loop ended")

if __name__ == '__main__':
    main()

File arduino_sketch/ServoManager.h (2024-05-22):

#ifndef ServoManager_h
#define ServoManager_h

#include "Config.h"
#include "InverseKinematics.h"

// Left Leg
ServoEasing ServoLLH; // Hip
ServoEasing ServoLLK; // Knee
ServoEasing ServoLLA; // Ankle
// Right Leg
ServoEasing ServoRLH; // Hip
ServoEasing ServoRLK; // Knee
ServoEasing ServoRLA; // Ankle
// Neck tilt
ServoEasing ServoNT;
// Neck pan
ServoEasing ServoNP;

InverseKinematics ik;

class ServoManager
{
public:
    double currentX, currentY;
    void doInit()
    {
        // IMPORTANT: Communication from Pi uses index, these must be attached in the same order as they are referenced in the pi config
        if (backpack == true)
        {
            ServoLLH.attach(PIN_SLLH, PosBackpack[0]);
            ServoLLK.attach(PIN_SLLK, PosBackpack[1]);
            ServoLLA.attach(PIN_SLLA, PosBackpack[2]);
            ServoRLH.attach(PIN_SRLH, PosBackpack[3]);
            ServoRLK.attach(PIN_SRLK, PosBackpack[4]);
            ServoRLA.attach(PIN_SRLA, PosBackpack[5]);
        }
        else {
            ServoLLH.attach(PIN_SLLH, PosStart[0]);
            ServoLLK.attach(PIN_SLLK, PosStart[1]);
            ServoLLA.attach(PIN_SLLA, PosStart[2]);
            ServoRLH.attach(PIN_SRLH, PosStart[3]);
            ServoRLK.attach(PIN_SRLK, PosStart[4]);
            ServoRLA.attach(PIN_SRLA, PosStart[5]);
        }
        ServoNT.attach(PIN_SNT, PosStart[6]);
        ServoNP.attach(PIN_SNP, PosStart[7]);

        // Initialise IK with min and max angles and leg section lengths
        ik.doInit(PosMin[3], PosMax[3], PosMin[4], PosMax[4], PosMin[5], PosMax[5], LEG_LENGTH_THIGH, LEG_LENGTH_SHIN, LEG_LENGTH_FOOT);

        // Loop over ServoEasing::ServoEasingArray and attach each servo
        for (uint8_t tIndex = 0; tIndex < SERVO_COUNT; ++tIndex)
        {
            // Set easing type to EASING_TYPE
            ServoEasing::ServoEasingArray[tIndex]->setEasingType(EASING_TYPE);
            ServoEasing::ServoEasingArray[tIndex]->setMinMaxConstraint(PosMin[tIndex], PosMax[tIndex]);
        }
        // Wait for servos to reach start position.
        delay(3000);
        cLog("Servos initialised");
    }

    // Adjust hips to compensate for angle of body
    // Read pitch (input from MPU6050) and adjust hips accordingly
    void hipAdjust(double pitch)
    {
        double startingOffset = 3.5;
        
        double threshold = 5.0; // Do not move if less than this
        #ifdef MPU6050_DEBUG
        Serial.print("Pitch:");
        Serial.print(pitch);
        Serial.print(" TH:");
        Serial.print(threshold+startingOffset);
        Serial.print(" TL:");
        Serial.println(-threshold+startingOffset);
        #endif
        if (pitch < threshold+startingOffset && pitch > -threshold+startingOffset)
        {
            return;
        }

        if (abs(pitch) > threshold) { 
          pitch = pitch*0.5;
        }
        ik.hipAdjust(ik.hipAdjustment - pitch);
        moveSingleServo(0, pitch, true);
        moveSingleServo(3, -pitch, true);
    }

    void moveServos(int *Pos)
    {
        for (uint8_t tIndex = 0; tIndex < SERVO_COUNT; ++tIndex)
        {
            if (Pos[tIndex] == NOVAL)
            {
                // Serial.println("NOVAL FOUND");
                continue;
            }
            if (Pos[tIndex] != -1)
                moveSingleServo(tIndex, Pos[tIndex], false);
            else
                moveSingleServo(tIndex, moveRandom(tIndex), false); // If scripted value is -1, generate random position based on range of currently indexed servo
        }
        // setEaseToForAllServosSynchronizeAndStartInterrupt(tSpeed);
    }

    void moveSingleServoByPercentage(uint8_t pServoIndex, int pPercent, boolean isRelative) {
        // Serial.print("PosMin: ");
        // Serial.print(PosMin[pServoIndex]);
        // Serial.print(" PosMax: ");
        // Serial.print(PosMax[pServoIndex]);
        // Serial.print(" Relative pos change in %: ");
        // Serial.print(pPercent);
        int realChange = map(abs(pPercent), 0, 100, PosMin[pServoIndex], PosMax[pServoIndex]);
        // Serial.print(" in degrees: ");
        // Serial.print(realChange);
        if (isRelative) {
            realChange = realChange - PosMin[pServoIndex]; // Account for min value ONLY if relative
        }
        if (pPercent < 0)
        {
            realChange = -realChange;
        }
        // PiConnect::write_i16(realChange);
        moveSingleServo(pServoIndex, realChange, isRelative);
    }

    void moveSingleServo(uint8_t pServoIndex, int pPos, boolean isRelative)
    {
        if ((backpack == true || restrainingBolt == true) && pServoIndex < 6)
        {
            // Serial.println("Backpack or restrained mode, skipping leg servos");
        }
        else if (isRelative)
        {
            ServoEasing::ServoEasingNextPositionArray[pServoIndex] = ServoEasing::ServoEasingNextPositionArray[pServoIndex] + pPos;
        }
        else
        {
            ServoEasing::ServoEasingNextPositionArray[pServoIndex] = pPos;
        }
        // Return actual value to Pi
        PiConnect::write_i16(ServoEasing::ServoEasingNextPositionArray[pServoIndex]);
    }

    void moveLegsAndStore(int x, int y, int *store)
    {
        moveLegs(x, y);
        for (uint8_t tIndex = 0; tIndex < SERVO_COUNT; ++tIndex)
        {
            store[tIndex] = ServoEasing::ServoEasingNextPositionArray[tIndex];
        }
    }

    // function moveLegs that returns an int array
    void moveLegs(int x, int y)
    {
        float hipAngleL, kneeAngleL, ankleAngleL, hipAngleR, kneeAngleR, ankleAngleR;
        currentX = x;
        currentY = y;
        // solve left leg
        ik.inverseKinematics2D(x, y, hipAngleL, kneeAngleL, ankleAngleL);
        // solve other leg
        ik.calculateOtherLeg(hipAngleL, kneeAngleL, ankleAngleL, hipAngleR, kneeAngleR, ankleAngleR);
        // Assign angles and move servos (cast float to int)
        int thisMove[SERVO_COUNT] = {(int)hipAngleL, (int)kneeAngleL, (int)ankleAngleL, (int)hipAngleR, (int)kneeAngleR, (int)ankleAngleR, NOVAL, NOVAL};
        moveServos(thisMove);
    }

    void demoAll()
    {
        setSpeed(SERVO_SPEED_MIN);
        // Cycle through all poses and move all servos to them
        for (uint8_t tPoseIndex = 0; tPoseIndex < sizeof(Poses) / sizeof(Poses[0]); ++tPoseIndex)
        {
            moveServos(Poses[tPoseIndex]);
            delay(1000);
            moveServos(PosRest);
            delay(2000);
        }
    }

    void setSpeed(uint16_t pSpeed)
    {
        tSpeed = pSpeed;
        setSpeedForAllServos(tSpeed);
        //        cLog(F("Speed set: "));
        //        cLog((String) tSpeed);
    }

    uint16_t getSpeed()
    {
        return tSpeed;
    }
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

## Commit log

2019-06-04 LED test
2019-06-15 Shutdown timer WIP
2019-06-15 Schematic v1.0
    [circuit v1_0.fzz]
2019-09-12 Servos with acceleration / deceleration curves
2019-09-14 Stepper module. Keyboard input for pan / tilt
2019-09-17 Linear Actuator
2019-09-20 WIP Power Management
2019-09-20 Power management tests + kwargs
2019-09-22 Power thread management
    [circuit v3.fzz]
2019-09-22 Manage power tests
2019-09-22 Safe handling of servo range violation
2019-09-24 WIP Stepper
2019-10-03 Digital sensor module
2019-10-04 WIP: Case layout
2019-12-08 Temperature, speech recognition, install script
2019-12-09 Working hotword, threaded hotword and speech recognition with google. Say 'robot' then speak.
2019-12-12 9 LEDs
2019-12-15 Support serial comms to Arduino inc pin activation
2019-12-21 Temporary led management
2019-12-21 Refactor LED and audio enable to use pubsub
2019-12-21 New circuit (poor layout)
    [Matrix 8x8 Game.fzz, RUR Circuit.fzz, circuit v2.fzz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]
2020-04-28 Fix servos
2020-09-04 Clean up files
    [RUR Circuit.fzz, circuit v1_0.fzz, circuit.fzz]
2020-11-02 Random behaviour & LED exit fixes
    [led.py, main.py, servo.py]
2020-11-10 Updated servo control + pin read
2020-11-10 Battery safe shutdown
2020-11-19 Complete battery monitor
2020-11-20 Fixed all servos
2020-12-15 Updated servo increment WIP
2020-12-15 No buffer on servo movement
2021-01-24 Servo key binding + braillespeak
    [braillespeak.py, config.py, main.py]
2021-01-30 Servos callibrated. Standing and crouching
2021-02-14 v2 circuit
    [Lower Feb 2021.fzz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]
2021-02-15 Modified PCBs
    [Lower Feb 2021.fzz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]
2021-02-17 Prepping files for PCB upgrades
2021-02-17 Power manager + some other notes
2021-02-18 Refactor for PCB changes
2021-02-19 Power management & LED effects
2021-02-19 LED animations work but thread stop doesn't
    [led.py]
2021-02-19 thread fix
2021-02-19 Thread rainbows
2021-03-17 Configure leg servos and eye index
2021-03-23 Tweak servos and disable pan temporarily
2021-04-01 Add minimum match threshold to filter false positives
2021-04-02 Handle sleep + Fixes
    [led.py, main.py, personality.py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]
2021-04-02 Added battery logger to determine return value range
2021-04-04 Fix battery monitor
2021-04-04 Save multiple matches from a frame. Improved FPS
2021-04-04 Cleanup and shutdown correctly on SIGTERM
    [config.py, led.py, main.py]
2021-04-04 Disable speech until errors can be resolved
    [main.py]
2021-04-05 Improved battery monitor
2021-04-07 Ignore 0 readings on battery until that issue can be resolved. Reinstate shutdown script
2021-04-07 Disable relay off state to debug power issue
    [power.py]
2021-04-08 Revert relay changes
2021-04-11 Fix nightly loop and training
    [config.py, led.py, main.py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]
2021-06-12 Improved animations. Disabled battery monitor in hardware and code
2021-08-10 Fix face tracking and improve behaviour
    [animate.py, keyboard.py, main.py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]
2021-08-13 Improved power management and vision
2021-12-04 Include STLs
    [back_case.stl, front_case.stl, head_bottom.stl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]
2021-12-04 Rename folder
    [back_case.stl, complete.stl, front_case.stl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]
2021-12-13 Personality: refactor
    [RUR Circuit.fzz, circuit v1_0.fzz]
2021-12-15 Improved personality and LED management
2021-12-31 Performance improvements using threading
2021-12-31 Performance improvement using threading on tracking
2021-12-31 Upgrade LEDs
2022-02-11 Monitor temperature. Improve gamepad functionality
2022-05-13 Fix speech recognition for MEMS mics
    [main.py, speechinput.py]
2022-07-30 Resolved power issue, bind to python 3.5
    [buzzer.py, main.py, personality.py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]
2023-03-17 Include test kinematics
2023-04-06 Re-integrate pi and arduino.
2023-04-06 WIP IK Integration
    [body.fzz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]
2023-04-08 Reposition legs so that forward knee is no longer used
    [Config.h, ServoManager.h]
2023-04-08 Calibrate legs
2023-04-22 Calibrate to new PCB
2023-05-13 Fix PCB
    [body.fzz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]
2023-05-13 Adjust PCB
    [body.fzz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]
2023-05-24 Reconfigure servos for v3
2023-05-27 Update circuits
    [body.fzz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]
2023-05-28 Adjust leg compensation
2023-05-29 Basic communication working. Needs reconfiguring all pi servo positions
2023-05-29 Disable any leg animations and remove references to third neck servo
2023-05-29 Add ability to flag servo move as relative for handling in arduino (untested)
2023-05-30 Trigger single servo movement in sleep mode
2023-05-30 Absolute servo movement in place
2023-06-01 Attempt to fix relative position
    [ServoManager.h]
2023-06-02 Fix relative position animations
    [ServoManager.h, servo.py]
2023-07-21 Handle object detection and face detection switching
2023-07-28 WIP: Config as YAML files instead of python
    [servos.yml]
2023-07-29 Add documentation to yaml
    [servos.yml]
2023-07-29 Added translator and attached to logger
2023-07-29 Fix issues after testing
    [main.py]
2023-07-31 Neopixel over i2c
2023-11-01 First pass at new PCB for head
    [v4head.kicad_pcb, v4head.kicad_sch]
2023-11-14 Updates to PCB
    [v4head.kicad_pcb, v4head.kicad_sch]
2023-11-16 Updates to circuit
    [v4head-B_Cu.gbr, v4head-B_Mask.gbr, v4head-B_Paste.gbr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]
2023-11-16 Swap TX & RX to align with LLC
    [v4head.kicad_pcb, v4head.kicad_sch]
2023-11-16 Update annotations
    [v4head-B_Cu.gbr, v4head-B_Mask.gbr, v4head-B_Paste.gbr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]
2023-11-17 Final version 1.0. Added decoupling caps to neopixels.
    [v4head-B_Cu.gbr, v4head-B_Mask.gbr, v4head-B_Paste.gbr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]
2023-11-17 Added version number
    [v4head-B_Cu.gbr, v4head-B_Mask.gbr, v4head-B_Paste.gbr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]
2023-12-16 Stable on Pi 5. Disabled modules with issues temporarily. Created sentiment analysis behaviour
    [piservo.yml]
2023-12-22 Make eye glow when using camera
2024-03-11 Servo adjust
    [servos.yml]
2024-03-13 Fix pi movements and animations
    [servos.yml]
2024-05-10 Improvements, backpack + restraining bolt support
2024-10-14 Allow manual selection of serial port
    [servos.yml]
2024-10-18 Fixed to allow boot
    [main.py]
2024-10-18 Improve visibility of distance to center of camera
2024-10-23 Calibrating X, disabled Y
2024-10-24 Improved tracking
    [servos.yml]
2024-10-26 Implemented dynamic modules. Archived untested modules.
    [piservo.yml, servos.yml]
2024-10-26 Adjust config
    [piservo.yml]
2024-10-26 Manage dependencies dynamically using config files
    [piservo.yml, servos.yml]
2024-12-20 Fixes to install (also applies to pi 5)
    [main.py]
2024-12-30 Beginning of SPI support
2024-12-31 Successful test of SPI neopixels
2025-03-09 Created unit test framework
